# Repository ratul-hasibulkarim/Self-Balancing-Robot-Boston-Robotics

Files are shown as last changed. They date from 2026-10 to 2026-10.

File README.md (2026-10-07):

# BOLT — a cute, 3D‑printable wheel‑legged balancing robot

**BOLT** balances on two wheels at the ends of two legs, like Boston Dynamics' *Handle* or ETH's *Ascento*. It drives fast, leans, crawls, carries a payload and jumps onto curbs. It follows coloured lines (day or night), avoids obstacles and halts when no path exists. It runs GPS missions from **Mission Planner** over the shortest road route, and you drive it from a **phone app**.

| | | |
|---|---|---|
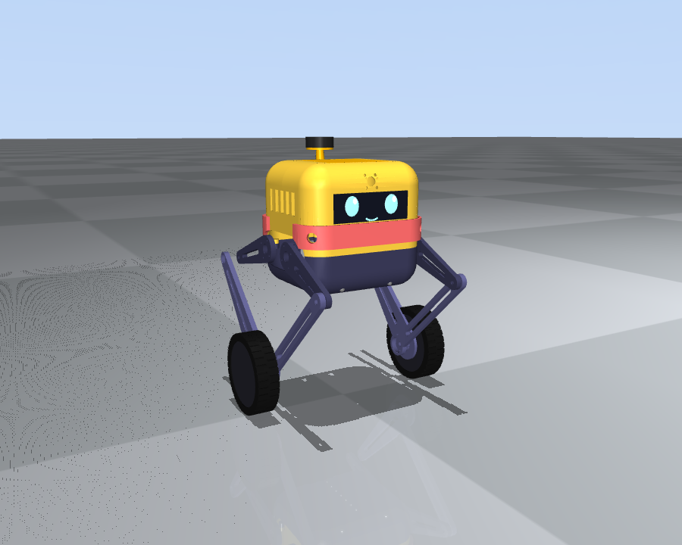
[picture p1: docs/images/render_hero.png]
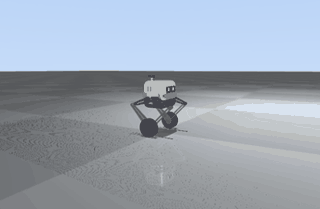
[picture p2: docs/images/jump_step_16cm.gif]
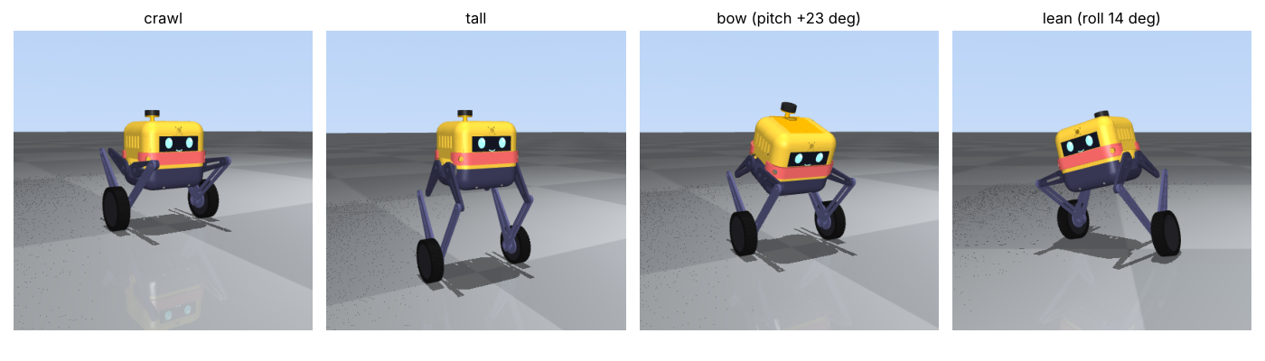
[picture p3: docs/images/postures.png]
|  |  |  |

> Everything here is designed and **tested in simulation** (MuJoCo + the real firmware controller + the real Raspberry Pi code). It has not been built yet. Expect to re‑tune gains on hardware. Read the limits section before you buy motors.

> **New to robotics?** Read the [beginner's guide](docs/guide/README.md). It covers how every part was designed, the physics, the linkages, how the simulations and design iterations were done, and how the electronics and code work.

## What's in this repository

| Deliverable | Where | |
|---|---|---|
| **1. 3D‑printable parts (solid parts)** | `cad/stl/*.stl` (22 parts, print‑oriented) · parametric generator `cad/build_parts.py` · assembly `cad/assembly_nominal_pose.stl` | [print & build guide](docs/05_print_and_build.md) |
| **2. Simulation + test‑driven design iterations** | `sim/` — MuJoCo model, LQR design, 15‑test suite, 3 design iterations, brain‑in‑the‑loop demos | [simulation report](docs/04_simulation_report.md) |
| **3. Control code** | `firmware/` — Teensy 4.1, 1 kHz balance + 5‑bar legs + jump state machine, CAN motor drivers · `companion/` — Raspberry Pi 5 brain (line following, A* routing, obstacle halt, MAVLink) | [software guide](docs/06_software.md) |
| **4. Circuit diagrams and settings** | `electronics/*.svg/.png` · pin maps, motor/Pi/GPS/Mission Planner settings | [electronics & settings](docs/03_electronics_and_settings.md) |
| **5. Controller app** | `app/` — installable phone app (PWA) served by the robot | [software guide §6.4](docs/06_software.md#64-controller-app-app) |
| Design rationale, COM, requirement traceability | | [design overview](docs/01_design.md) · [bill of materials](docs/02_bom.md) |
| **Full explanation for beginners** | physics, mechanism, CAD, simulation & iterations, electronics, code walkthrough | [docs/guide](docs/guide/README.md) |

## The robot in numbers (final design V3, simulation)

* 6.4 kg, 0.49 m tall, 0.40 m wide. Ride height is adjustable from 0.21 to 0.39 m (hip).
* 4 × DM‑J4310 hip actuators drive two 5‑bar legs; 2 × MF9025 hub motors drive the 150 mm wheels. Power is a 6S 5000 mAh LiPo.
* Teensy 4.1 runs the 1 kHz balance loop. Raspberry Pi 5 handles vision, navigation, the app and MAVLink. Two 220° fisheye cameras give 360° coverage.
* Speed: **2.0 m/s** tracked cleanly. Turns at 2 rad/s while doing 1.5 m/s.
* Slopes: **25°** ramps climbed and held. **16°** side slopes with the body kept level.
* Rough ground: **8 cm** bumps at 1.5 m/s. Recovers cleanly from a **10 N·s** shove.
* Payload: **3 kg**, in a bay centred on the hip axis.
* Jumps: **22 cm** wheel clearance. Steps up onto **20 cm** steps (100 % at a 1 m/s run‑up). Hops over **14 cm** obstacles.
* Posture: tilts **±23°**, leans **±15°**, crawls under a **0.42 m** bar.
* Line following: **2.6 cm** mean error, day and night (auto headlight/IR).
* Navigation: A* detours around obstacles, re‑routes around blocked roads, and **halts** if no path exists.

## Limits — read this first

* **Multi‑step stairs don't work reliably.** Single steps and curbs up to 20 cm work. House stairs (25–30 cm treads) fail: there isn't enough run‑up between steps for these hip motors. The fix is stronger hip actuators; see [§4.6](docs/04_simulation_report.md).
* **Self‑righting** from lying flat doesn't work yet. The robot goes limp and you stand it up.
* **Camera‑based step locating is experimental.** Start "Step up" with BOLT 0.5–0.8 m in front of the step.
* Datasheet values to **verify on your parts**: motor bolt patterns, the MF9025 torque constant, and CAN details. They are parameters in the code.

## Quick start

```bash
pip install mujoco numpy scipy matplotlib trimesh manifold3d opencv-python-headless pymavlink aiohttp pyyaml pytest
python3 cad/build_parts.py                    # STLs + mass report
python3 sim/lqr_design.py                     # controller gains (also writes the firmware header)
python3 sim/test_suite.py V3                  # run the 15 requirement tests
python3 sim/companion_sim.py --demo app       # drive the simulated robot from the real app: http://localhost:8080
python3 -m pytest -q companion/tests          # firmware<->Pi link byte compatibility, GPS, A*, re-routing
cd firmware && pio run                        # build the Teensy firmware
```

## Repository map
```
design/      params.py (single source of truth, V1..V3), kinematics.py (5-bar)
cad/         build_parts.py -> stl/, assembly/, mass_report.json
sim/         robot_model.py, lqr_design.py, controller.py (ctypes), simulator.py,
             test_suite.py, companion_sim.py, make_report.py, results/
firmware/    src/main.cpp, src/config.h, lib/bolt_core (controller, shared with sim),
             lib/bolt_drivers (CAN motors, IMU, sonar, eyes), lib/bolt_link, tools/check_build.sh
companion/   robot_brain/ (behaviors, perception, navigation, mission, app_server, link, gps),
             config.yaml, tools/bolt_cli.py, systemd/, tests/
app/         index.html, app.js, style.css, manifest + service worker (PWA)
electronics/ make_diagrams.py -> power_distribution.*, signal_wiring.*
docs/        01_design .. 06_software, images/, guide/ (beginner's guide, 8 chapters)
```

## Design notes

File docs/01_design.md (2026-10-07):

# 1 · Design overview — BOLT

BOLT is a **wheel‑legged balancing robot** in the spirit of Boston Dynamics' *Handle* and ETH's *Ascento*: two legs, each ending in a driven wheel. A leg can change length and angle, so the same machine can **balance like a Segway, crouch, crawl, lean, tilt and jump**.

BOLT

| | |
|---|---|
| Mass | 6.4 kg (body 4.2 kg, legs + wheels 2.2 kg), payload up to 3 kg (sim‑verified), 2 kg design value |
| Size | body 210 × 240 × 230 mm, track 364 mm, overall width 404 mm |
| Height | 0.49 m standing · 0.42 m crawling · hip 0.21–0.39 m (adjustable) |
| Legs | planar 5‑bar per side: hip motors 90 mm apart, thigh 140 mm, shin 250 mm, virtual leg 0.13–0.35 m |
| Actuators | 4 × DM‑J4310‑2EC (hips, 7 Nm peak, CAN) + 2 × LK MF9025v2 hub motors (wheels, 4 Nm, CAN) |
| Wheels | 150 mm, printed PETG‑CF rim + TPU 95A tyre |
| Brains | Teensy 4.1 (1 kHz balance/legs) + Raspberry Pi 5 (vision, navigation, app, MAVLink) |
| Power | 6S LiPo 5000 mAh, slide‑in tray, hot‑swappable |
| Sensing | IMU ICM‑42688‑P, 2 × 220° fisheye cameras (360° view), 4 × ultrasonic, 2 × IR drop‑off sensors, GPS + compass (M10 puck) |

---

## 1.1 Why a wheel‑legged robot?

| Requirement | What the architecture gives |
|---|---|
| Balance on rough / inclined ground | Wheels balance (inverted pendulum); legs act as active suspension and keep the body level (roll compensation on side slopes, pitch on ramps). |
| Run fast | Wheels are 5–10× more efficient and faster than walking legs. |
| Jump steps / obstacles | Both hip motors of a leg push together → 80–165 N per leg (4–8× what it takes to hold the body) → 22 cm wheel clearance in simulation. |
| Tilt / crawl | Leg length 0.13–0.35 m and leg angle are independent → body pitch ±23°, roll ±15°, low crawl stance. |

A pure two‑wheeler can't jump or crawl; a quadruped is slow, heavy and complex. Two legs with wheels is the sweet spot.

## 1.2 Centre of mass — requirement 1

The balance law is an LQR on the "wheel + leg + body" pendulum (see [06_software.md](06_software.md)). What makes it robust on slopes and rough ground is **where the mass sits**:

1. **Fore–aft: on the hip axis.** Battery, payload bay and electronics are arranged so the body COM is within 5 mm of the hip axis in *x*. The leg then stands vertical at rest, the hip motors carry almost no static torque, and acceleration/braking is symmetric.
2. **Vertical: just above the hip axis (+24 mm).** The 780 g battery is slung *below* the hip axis between the hip motors; the payload bay sits *on* the axis. This keeps the body's pitch inertia small (fast attitude control, quick self‑levelling) and means rotating the body relative to the legs (tilt, bow, landing) costs almost no torque.
3. **Lateral: centred, wide track.** 364 mm track and a low whole‑robot COM (0.25 m) give a large lateral stability margin; on side slopes the legs differentially lengthen so the body stays level (sim: < 2° body roll on a 16° side slope).
4. **Leg mass at the top.** The hip motors are on the body, not on the legs (that's the point of the 5‑bar), so the legs are light (0.24 kg of printed links each) and swing fast.

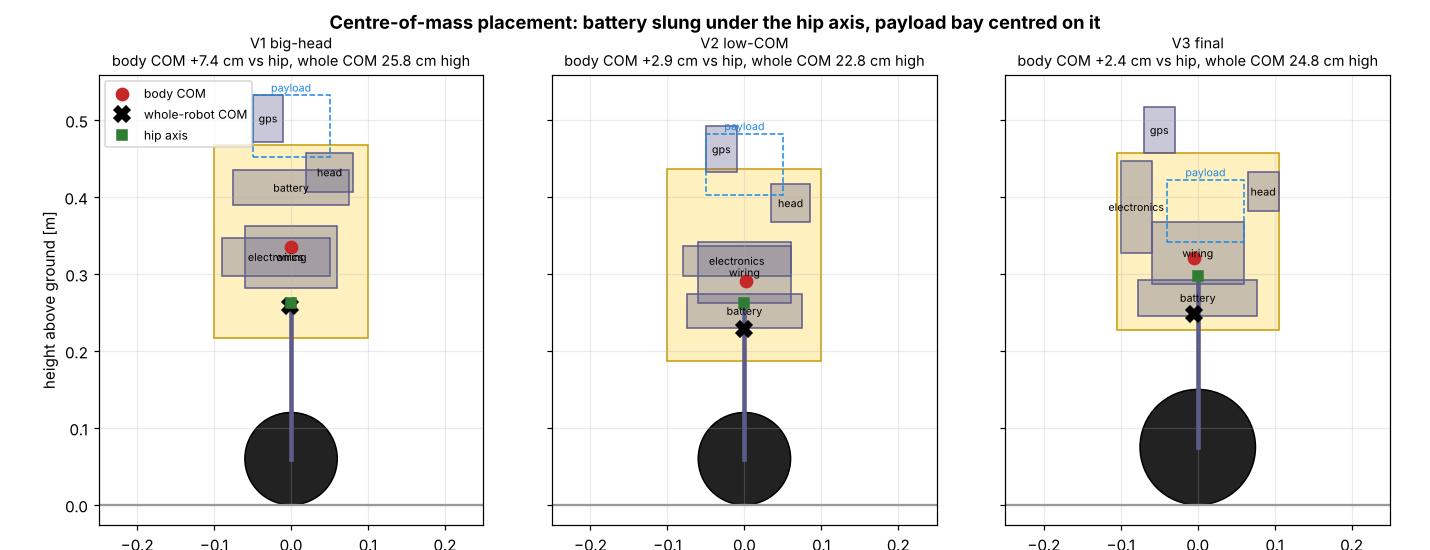
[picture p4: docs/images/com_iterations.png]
COM placement over the three design iterations


The first sketch (V1, "big‑head" — battery and sensors up in the head for a cartoon look) had the body COM 74 mm above the hip; V2 moved the battery under the hip axis (+29 mm); V3 sank the payload bay into the body centre (+24 mm) and grew the wheels. See [04_simulation_report.md](04_simulation_report.md) for what each change bought.

## 1.3 Mechanical layout

```
          GPS puck (stub mast)          payload lid (magnetic)
               |                               |
      +--------+--------- shell (PETG) --------+--------+
      | electronics |      PAYLOAD BAY        | face     |
      |   SLED      |   120 x 124 x 110 mm    | screen,  |
      | (Pi 5,      |   centred on hip axis   | eyes,    |
      |  Teensy,    |                         | fisheye  |
      |  bucks)     |== hip motors (4) ===== =| sonar    |
      |             |  BATTERY 6S (slung low) |          |
      +-----------------  belly pan (PETG-CF) -----------+
             5-bar legs outside the side plates
```

* **Structural core**: two 8 mm PA‑CF side plates carry the four hip motors and are tied by a floor plate (with battery rails) and a top frame. The shell is cosmetic + protective and attaches with 6 × 3 mm magnets — no tools to open.
* **Legs**: per side two thighs (on the hip motors) and two shins meeting at the wheel axle; 608‑2RS bearings at knees and the foot joint; the rear shin carries the wheel motor stator.
* **Bumpers**: TPU 95A "cheeks" front and rear take falls and wall hits; the belly pan has TPU skid ribs.

### Cute character — requirement 3
BOLT is a chunky rounded box ("toaster‑bot") with a dark face screen, two glowing WS2812 ring **eyes** that change expression (normal, happy while jumping, sleepy when off, alert when blocked, angry on error), red bumper "cheeks", and a little antenna stub with the GPS puck. All parts print on a 256 mm bed without supports except the shell openings. See [05_print_and_build.md](05_print_and_build.md).

| front | side | rear / top |
|---|---|---|
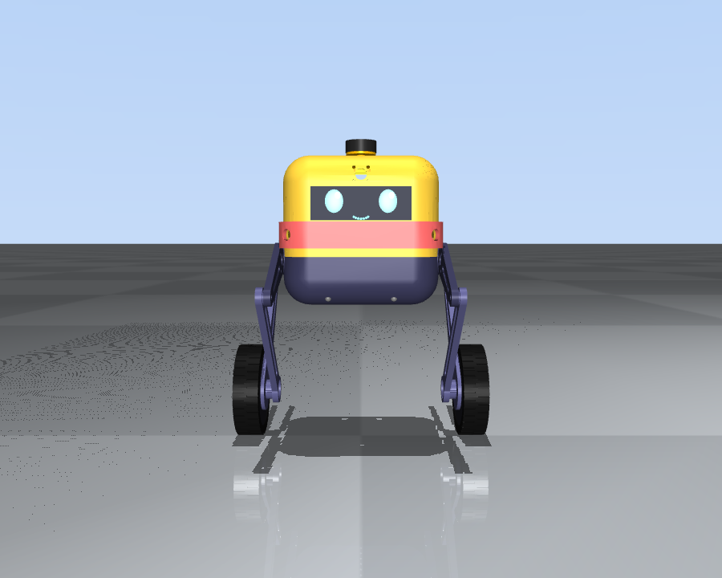
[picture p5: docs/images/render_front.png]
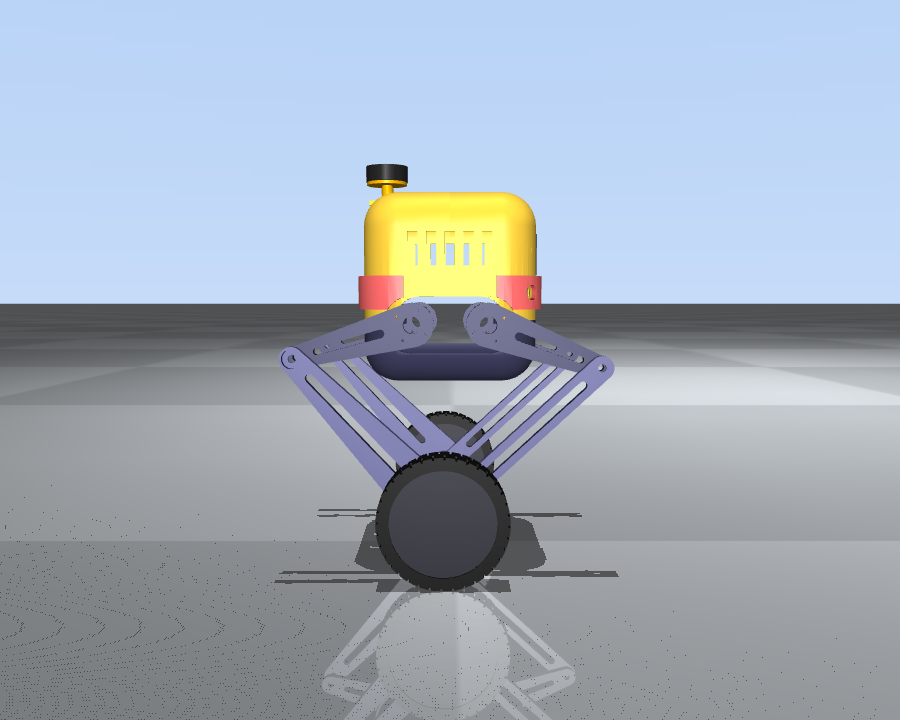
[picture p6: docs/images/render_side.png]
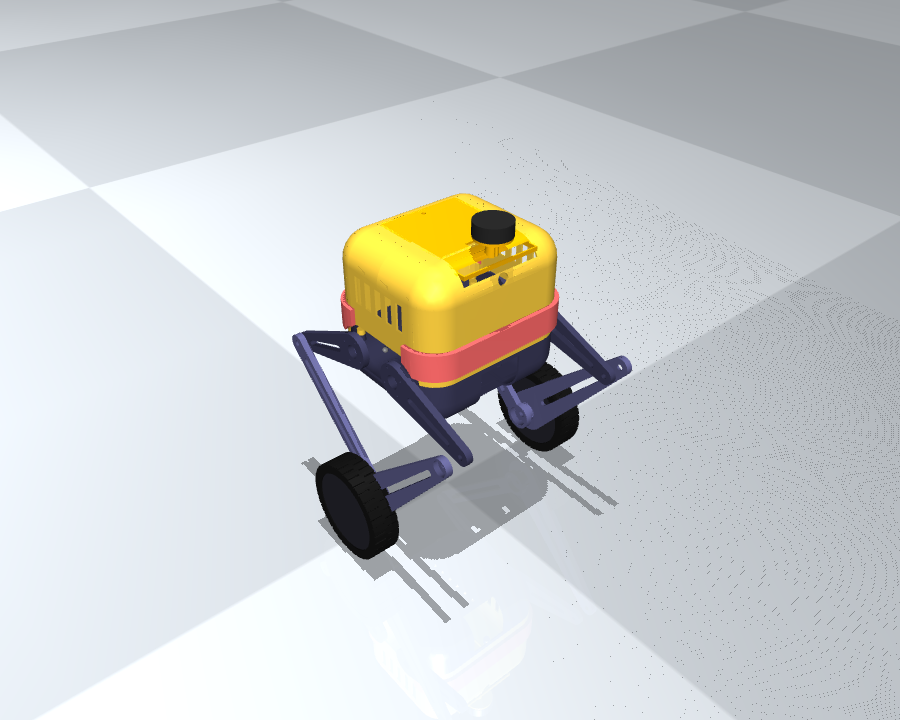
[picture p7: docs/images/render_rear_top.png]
|  |  |  |

## 1.4 Electronics that are handy to remove — requirement 2

* **Electronics sled**: a vertical cartridge (Raspberry Pi 5 on rubber grommets on one face, Teensy carrier with the IMU hard‑mounted + buck converters on the other). It slides into printed guides in the top frame, is clamped by two thumb screws (rigid, so the IMU sees the true body motion) and **pulls straight up** through the roof after lifting the magnetic cap. One 12‑pin locking connector (JST‑GH/Molex Micro‑Fit) + one XT30 carry everything — no loose wires.
* **Battery**: slide‑in tray from the rear with a snap latch; XT90‑S anti‑spark connector.
* **Payload bay**: separate magnetic lid; drain holes and tie‑down eyelets.
* **Motors**: each motor has its own XT30 + 4‑pin CAN JST‑GH pigtail, replaceable without opening the sled.

## 1.5 Cameras — requirement 4: maximum view with minimum cameras

Two **220° M12 fisheye** cameras (Arducam IMX219 NoIR), back‑to‑back at the top front (forehead, 10° down) and rear. Two 220° hemispheres overlap by 40°, so **two cameras see the full 360°** around the robot including the floor right in front of the wheels (needed for line following and step detection). The Pi 5 has exactly two CSI ports. NoIR sensors + 850 nm IR LEDs let them see in the dark.

## 1.6 Fast running without damaging the electronics — requirement 5

| Measure | Where |
|---|---|
| 150 mm wheels: 2 m/s at 70 % of motor no‑load speed (torque reserve for balance) | params / sim |
| Speed‑dependent ride height (lower when fast) and acceleration limit 2.5 m/s² | controller |
| Raspberry Pi on rubber grommets; IMU hard‑mounted but with its on‑chip anti‑alias filter (ODR/10) | CAD / firmware |
| TPU bumpers + TPU tyres (shock absorbing) | CAD |
| Soft landings: leg stroke kept for touchdown, damping doubled in the LAND phase | controller |
| 1000 µF low‑ESR + TVS on the motor bus (regen spikes when braking / landing) | wiring |
| Fall detection → motors limp (no thrashing into the ground) | controller |
| Separate always‑on logic supply; e‑stop only kills motor power | wiring |
| Motor CAN timeout (50 ms), Teensy watchdog (100 ms), Pi command timeout (300 ms) | firmware |
| Battery under‑voltage: slow down, then sit and switch motors off | firmware |

## 1.7 Requirement traceability

| # | Requirement | How BOLT does it | Verified in |
|---|---|---|---|
| 1 | COM for rough / inclined terrain | §1.2, gain‑scheduled LQR, roll levelling | sim: 25° ramps, 16° side slopes, 8 cm bumps at 1.5 m/s |
| 2 | Electronics easy to remove | §1.4 sled + tray + magnetic shell | CAD |
| 3 | Solid, cute, printable | PA‑CF structure, TPU bumpers, expressive eyes | CAD (all parts ≤ 256 mm, watertight STLs) |
| 4 | Cameras with max visibility | 2 × 220° fisheye = 360° | sim camera, line following |
| 5 | Run fast safely | §1.6 | sim: 2.0 m/s clean, turning 2 rad/s at 1.5 m/s |
| 6 | Jump steps / obstacles of variable height & distance | energy‑planned jump with edge‑distance timing | sim: step‑ups to 20 cm, hop 14 cm obstacle, flat jump 22 cm clearance (multi‑step stairs: see limits) |
| 7 | Tilt at variable angles / crawl | posture commands | sim: pitch ±23°, roll ±15°, crawl under 0.42 m |
| 8 | Carry a payload | sunken bay on the hip axis | sim: 3 kg drive + push |
| 9 | Avoid obstacles, run in the dark, follow coloured lines (no lidar) | sonar occupancy grid + A*, vision line follower + auto headlight/IR | SIL sim (real brain code) |
| 10 | Halt if no alternative path | local A* → turn‑and‑scan → road re‑route → HALT + report | SIL sim "boxed in" |
| 11 | Mission Planner GPS missions, shortest path | MAVLink rover endpoint + A* on a road graph | SIL sim with a pymavlink GCS |
| 12 | Phone controller: jump, dodge, tilt, climb… | PWA app served by the robot | headless browser test vs. sim |

## 1.8 Known limits (honest list)

* **Multi‑step stairs are not reliable.** Single steps/curbs up to 20 cm work every time in simulation at a 1 m/s approach. Consecutive hops need a 0.6 m+ landing between steps and even then fail intermittently on the final design (front knee clips the edge after a short run‑up). Normal house stairs (0.25–0.30 m treads) are **not** supported by this actuator set. Fix path: stronger hip actuators (e.g. DM‑J8009) for a standing‑start lunge jump, or a "knees‑back" leg variant.
* **Self‑righting** from lying flat is implemented but does not work yet in simulation — the robot goes limp (protecting itself) and waits for you to stand it up.
* **Autonomous step locating** (front camera → distance to a step edge) is experimental: accurate to ~2 cm at 0.5–0.9 m, but the full "Step up" action only works reliably when started ~0.7 m in front of the step.
* All results are **simulation** (MuJoCo + the real controller code + motor torque/speed limits + sensor noise/latency). Expect to re‑tune gains on the real robot ([06_software.md](06_software.md) §bring‑up).
* Motor bolt patterns, the MF9025 torque constant and CAN details are from datasheets of the versions I know; **verify against the batch you buy** (they're parameters in `cad/build_parts.py` and `firmware/src/config.h`).

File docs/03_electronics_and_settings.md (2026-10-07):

# 3 · Electronics, wiring and settings

Diagrams are generated by `electronics/make_diagrams.py` (SVG + PNG). Pin numbers come from `firmware/src/config.h` — if you change one, change both.

## 3.1 Power distribution

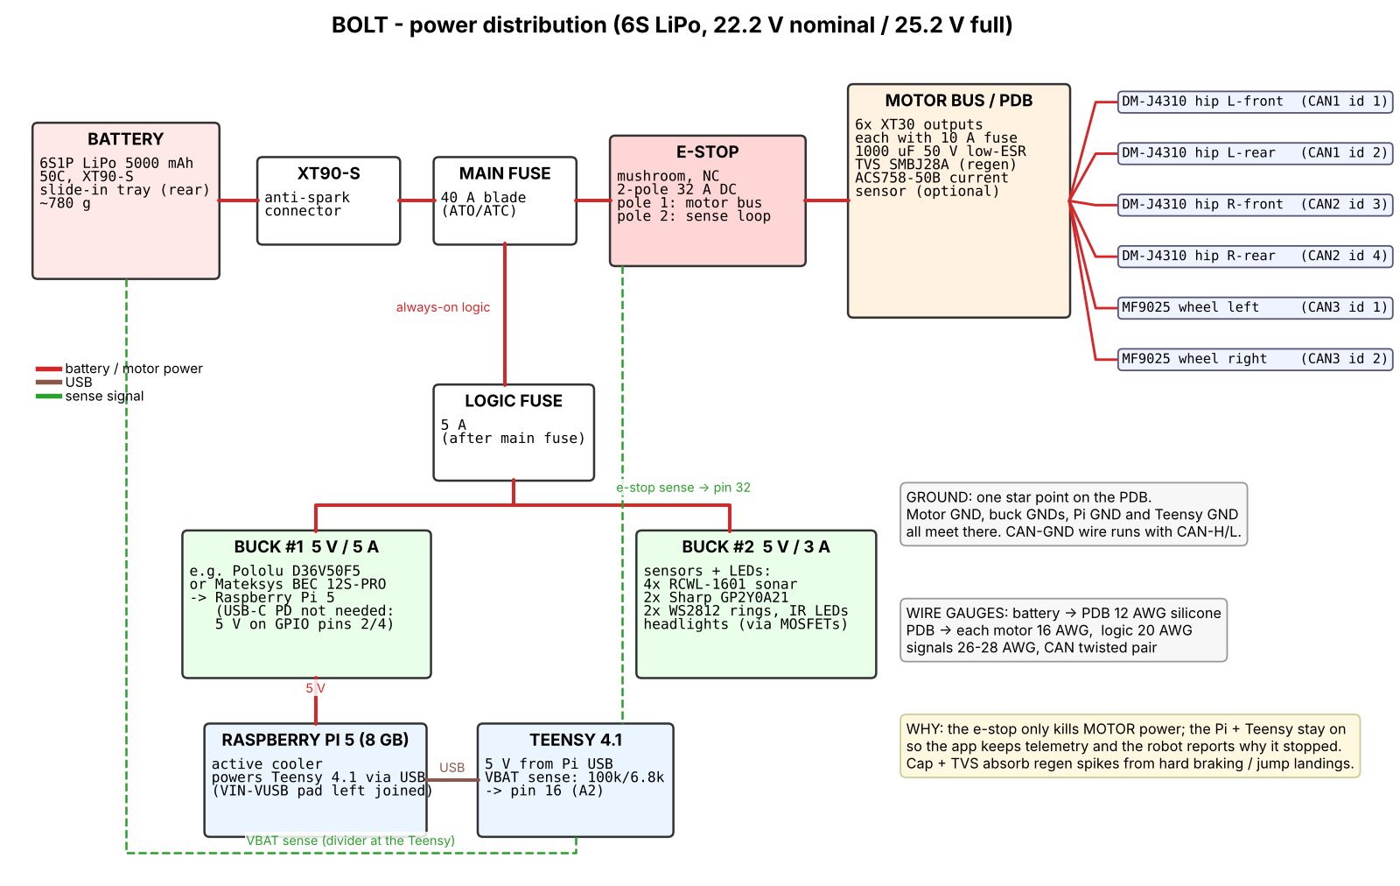
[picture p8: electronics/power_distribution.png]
power


* **One star ground** on the PDB. Never ground the Pi or Teensy through a different path than their supply.
* The **e‑stop cuts only motor power**. Pi + Teensy stay alive (logic fuse is upstream of the e‑stop), so the app still shows telemetry and why the robot stopped. Pole 2 of the e‑stop opens a sense loop on Teensy pin 32 → the controller also commands zero torque.
* **Regen protection**: hard braking and jump landings push current back into the bus. The 1000 µF low‑ESR capacitor and the SMBJ28A TVS at the PDB clamp the spikes (DM motors are rated 24 V nominal; a full 6S pack is 25.2 V — do **not** go to 8S).
* Pi 5 is fed 5 V directly on GPIO pins 2/4 (5 V) and 6 (GND) from a 5 A buck. Add `usb_max_current_enable=1` to `config.txt` (see §3.5), otherwise the Pi limits USB current because there is no USB‑PD negotiation.

## 3.2 Signal wiring

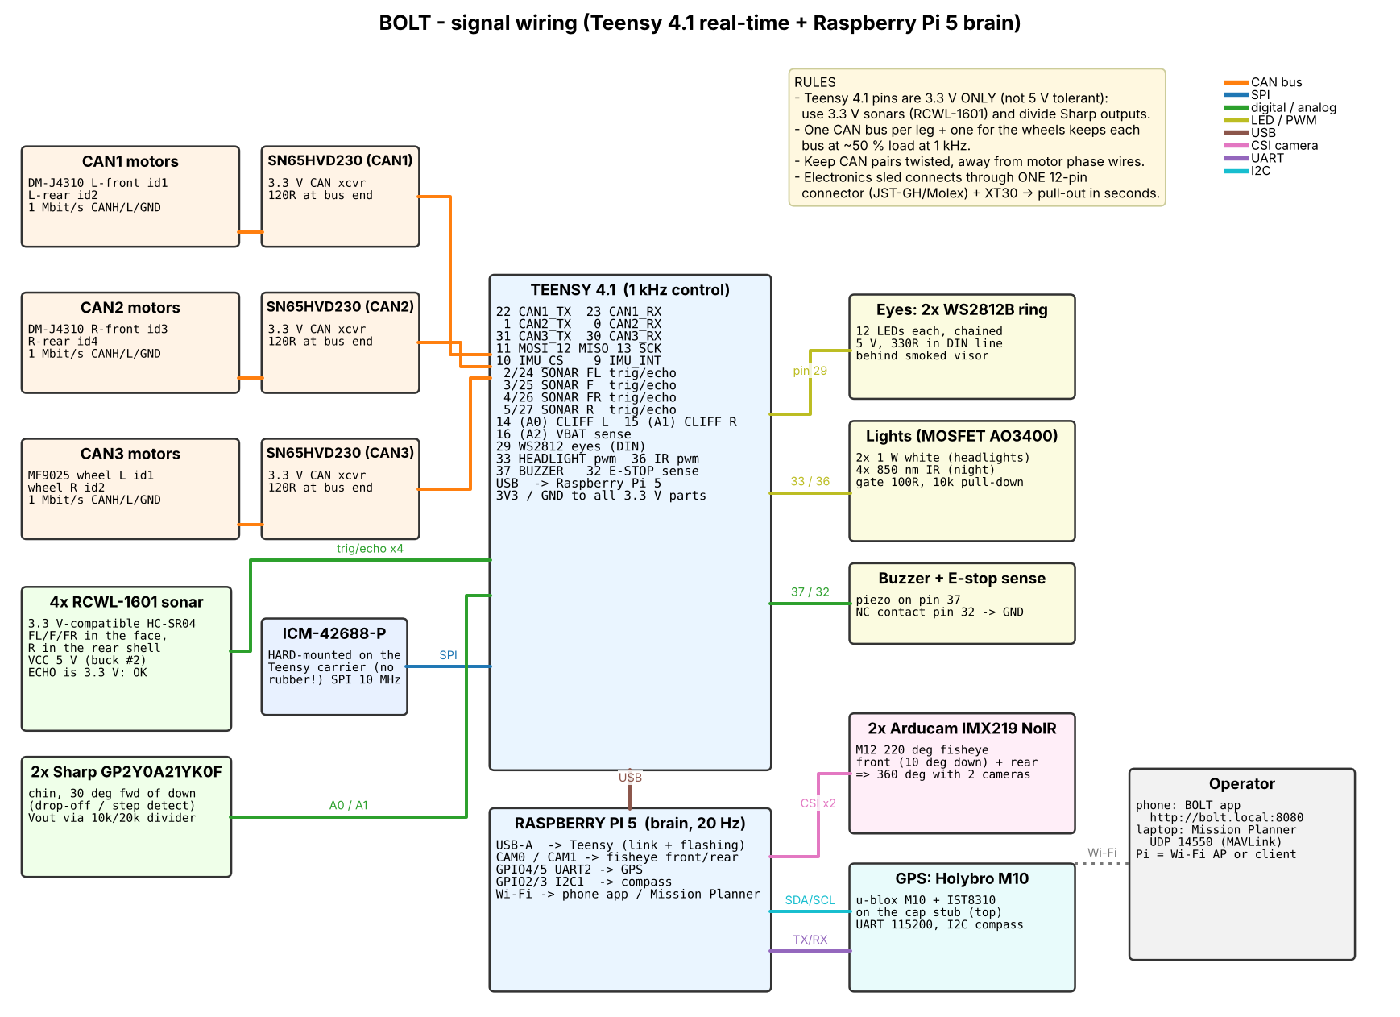
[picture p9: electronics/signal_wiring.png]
signals


### Teensy 4.1 pin map
| Pin | Function | Pin | Function |
|---|---|---|---|
| 22 / 23 | CAN1 TX / RX → left hips | 2 / 24 | sonar FL trig / echo |
| 1 / 0 | CAN2 TX / RX → right hips | 3 / 25 | sonar F trig / echo |
| 31 / 30 | CAN3 TX / RX → wheels | 4 / 26 | sonar FR trig / echo |
| 11 / 12 / 13 | SPI MOSI / MISO / SCK (IMU) | 5 / 27 | sonar Rear trig / echo |
| 10 / 9 | IMU CS / INT | 14 (A0) / 15 (A1) | Sharp cliff L / R (via 10k/20k divider) |
| 29 | WS2812 eyes DIN (330 Ω series) | 16 (A2) | VBAT sense (100k / 6.8k) |
| 33 | headlight PWM → AO3400 | 32 | e‑stop sense (INPUT_PULLUP, loop to GND) |
| 36 | IR LEDs PWM → AO3400 | 37 | buzzer |
| USB | Raspberry Pi (link + power + flashing) | 3V3 | IMU, CAN transceivers, sonar logic |

> Teensy 4.1 I/O is **3.3 V only**. That's why the sonars are RCWL‑1601 (3.3 V HC‑SR04 variant) and the Sharp outputs go through a divider.

### Raspberry Pi 5 connections
| Pi | Connected to |
|---|---|
| USB‑A (any) | Teensy 4.1 micro‑USB → `/dev/ttyACM0` |
| CAM0 / CAM1 (22‑pin) | front / rear fisheye camera |
| GPIO4 (TXD2) / GPIO5 (RXD2) | GPS RX / TX (UART2 → `/dev/ttyAMA2`) |
| GPIO2 (SDA1) / GPIO3 (SCL1) | GPS puck compass IST8310 (I²C 0x0E) |
| pins 2/4 + 6 | 5 V / GND from buck #1 |
| Wi‑Fi | phone app + Mission Planner |

### CAN buses
* **3 buses at 1 Mbit/s**: CAN1 = left hip motors (IDs 1, 2), CAN2 = right hip motors (IDs 3, 4), CAN3 = wheel motors (IDs 1, 2). At 1 kHz each bus carries 4 frames/ms ≈ 50 % load.
* Daisy chain each bus with twisted pair + a GND wire. **120 Ω at both ends**: most SN65HVD230 breakouts already have one (keep it at the Teensy end) and put one at the last motor (DM motors have a termination switch / solder pad).

## 3.3 Motor settings

### DM‑J4310‑2EC (Damiao debugging assistant, USB‑CAN adapter)
| Setting | Value |
|---|---|
| Control mode | **MIT** |
| CAN ID (slave) | 0x01 L‑front, 0x02 L‑rear, 0x03 R‑front, 0x04 R‑rear |
| Master ID (feedback) | 0x11 / 0x12 / 0x13 / 0x14 |
| Baud | 1 Mbit/s |
| PMAX / VMAX / TMAX | 12.5 rad / 30 rad/s / 10 Nm |
| CAN timeout | 50 ms (motor disables itself if commands stop) |
| Over‑temperature | 80 °C (default) |

Firmware sends pure torque (`kp = 0`, small `kd = 0.02` for smoothness). **Direction**: `HIP[i].sign` in `config.h` maps motor rotation to the controller's φ convention (CCW in the leg plane seen from the robot's right). After calibration, run `bolt_cli.py status`, move a leg by hand: extending the leg must *increase* L.

### LK‑TECH MF9025v2 (LK motor tool)
| Setting | Value |
|---|---|
| ID | 1 = left, 2 = right (frame id 0x141 / 0x142) |
| Bus | CAN, 1 Mbit/s |
| Control | torque loop, command 0xA1 (iq) |
| Protection | enable "communication interruption" stop (100 ms) |
| Firmware constants | `WHEEL_KT` (Nm/A) and `WHEEL_IQ_FULLSCALE_A` — **check your datasheet**; wrong values only scale the gains, but check the sign: positive wheel torque must roll the robot forwards |

## 3.4 Firmware settings (`firmware/src/config.h`)
* `CONTROL_HZ 1000`, `TELEMETRY_HZ 100`, `CMD_TIMEOUT_S 0.3` (no command → stop and hold balance).
* `CAL_PHI1/CAL_PHI4`: thigh angles in the calibration pose (legs folded on the printed end stops). Computed from the kinematics; don't change unless you change the legs.
* `BATT_LOW_V 21.0` (slow down), `BATT_CRIT_V 19.8` (motors off).
* `IMU_AXIS_MAP / IMU_AXIS_SIGN`: map the IMU chip axes to body axes (x forward, y left, z up).
* Gains: `firmware/lib/bolt_core/robot_config_generated.h` is **generated** by `python3 sim/lqr_design.py` — edit `design/params.py` / the weights in `sim/lqr_design.py`, not the header.

## 3.5 Raspberry Pi OS (Bookworm 64‑bit)
`/boot/firmware/config.txt` additions:
```ini
# cameras (two IMX219 on CAM0/CAM1)
camera_auto_detect=0
dtoverlay=imx219,cam0
dtoverlay=imx219,cam1
# GPS on UART2 (GPIO4/5) -> /dev/ttyAMA2, compass on I2C1
dtoverlay=uart2-pi5
dtparam=i2c_arm=on
# powered through the GPIO 5 V pins by a 5 A buck
usb_max_current_enable=1
```
Then:
```bash
sudo hostnamectl set-hostname bolt          # app at http://bolt.local:8080
sudo apt install -y python3-opencv python3-picamera2 python3-serial python3-yaml python3-aiohttp python3-numpy
pip install --break-system-packages pymavlink
sudo usermod -aG dialout,video bolt
# Wi-Fi hotspot for the field (phone + laptop join "BOLT"):
sudo nmcli dev wifi hotspot ifname wlan0 ssid BOLT password "bolt-robot"
sudo cp companion/systemd/bolt.service /etc/systemd/system/ && sudo systemctl enable --now bolt
```

## 3.6 GPS (u-blox M10, u‑center 2, once)
* UART1 baud **115200**, output **NMEA** GGA + RMC + GSA (disable GSV/GLL/VTG to save bandwidth).
* Navigation rate **10 Hz** (M10 supports 10 Hz with GPS+Galileo+BeiDou; drop GLONASS if needed).
* Dynamic platform model **Pedestrian** (good for ≤ 3 m/s ground robots), SBAS on.
* Save configuration to flash/BBR.
* Mount the puck on the cap stub (top of the robot) — as far from the motors as possible; the compass (IST8310) is optional for BOLT (heading is fused from IMU yaw + GPS course).

## 3.7 Mission Planner (ArduPilot GCS)
1. Laptop joins the robot's Wi‑Fi (or the same LAN). In `companion/config.yaml` set `mavlink.url` to `udpout:<laptop-ip>:14550` (or keep the broadcast default).
2. Mission Planner → top right: **UDP**, port **14550**, Connect. BOLT appears as a *Rover* (sysid 1) on the map with heading, speed, GPS and battery.
3. **Plan** tab → set Home, click waypoints → **Write WPs**. Supported: `WAYPOINT`, `LOITER_TIME`, `RETURN_TO_LAUNCH`, `CONDITION_DELAY`, `DO_JUMP`, `DO_CHANGE_SPEED`, plus `USER_1` (BOLT jump: p1 height m, p2 0=onto/1=over), `USER_2` (height/crawl), `USER_3` (tilt: p1 pitch°, p2 roll°).
4. **Data** tab → Actions: **Arm**, mode **Auto** (or "Mission Start"). `Hold` pauses, `RTL` returns home, right‑click → **Fly to here** = GUIDED go‑to.
5. Between waypoints BOLT drives the **shortest route over the road graph** (`companion/maps/roads.geojson`, export OSM `highway=*` lines for your area with QGIS/overpass‑turbo) with A*; it detours around obstacles, re‑routes around blocked roads and **halts with a status text** if no alternative exists.

## 3.8 First‑time calibration
1. Power with the **e‑stop pressed** (motors unpowered), connect to the Pi: `sudo systemctl stop bolt`.
2. `python3 tools/bolt_cli.py calibrate` with both legs folded against the printed end stops → offsets stored in Teensy EEPROM. The eyes stop being "angry" (uncalibrated) and turn normal.
3. `python3 tools/bolt_cli.py status`: tilt the robot nose‑down → pitch must go **positive**; roll left side up → roll positive; extend a leg by hand → L increases.
4. `tools/bolt_cli.py sonar` → check all four sonars and both cliff sensors.
5. Release the e‑stop, hold the robot upright on the floor, `tools/bolt_cli.py balance 10`. It should stand still; if it runs away, a sign in `config.h` is wrong (wheel or hip `sign`, or IMU map).

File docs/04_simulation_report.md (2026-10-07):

# 4 · Simulation, testing and design iterations

## 4.1 How the robot was simulated

* **Physics**: MuJoCo 3 (0.5 ms step, implicit integrator, elliptic friction cones). The model (`sim/robot_model.py`) is generated from `design/params.py` and the CAD mass report: a floating body, **closed‑chain 5‑bar legs** (equality constraints), real tyre/ground contact, the GPS puck and shins as colliders.
* **Controller = firmware**: `firmware/lib/bolt_core/bolt_controller.cpp` is compiled into a shared library and called through ctypes at 1 kHz — the simulator runs the exact code that is flashed onto the Teensy.
* **Realism added**: linear torque–speed envelopes of both motor types (back‑EMF limits), one control period of CAN latency, IMU/encoder noise, a speed‑dependent wheel velocity estimate, simulated ultrasonic cones, IR cliff sensors, a rendered front camera and a wandering virtual GPS.
* **Brain in the loop** (`sim/companion_sim.py`): the real Raspberry Pi code (`companion/robot_brain`) drives the simulated robot — line following from rendered images, A* obstacle detours, Mission Planner missions over real MAVLink/UDP, and the phone app over WebSocket.

Reproduce everything: see [06_software.md §6.5](06_software.md).

## 4.2 Design iterations

| | V1 "big head" | V2 "low COM" | V3 final |
|---|---|---|---|
| Idea | cartoon proportions: battery + sensors in the head | battery slung under the hip axis, wider track (300 → 364 mm) | 150 mm wheels, longer shins (jump stroke), payload bay sunk onto the hip axis, printed parts from CAD |
| Body COM above hip axis | +74 mm | +29 mm | +24 mm |
| Whole‑robot COM height | 0.26 m | 0.23 m | 0.25 m |
| Wheel Ø | 120 mm | 120 mm | **150 mm** |
| Mass | 5.7 kg | 5.7 kg | 6.4 kg |

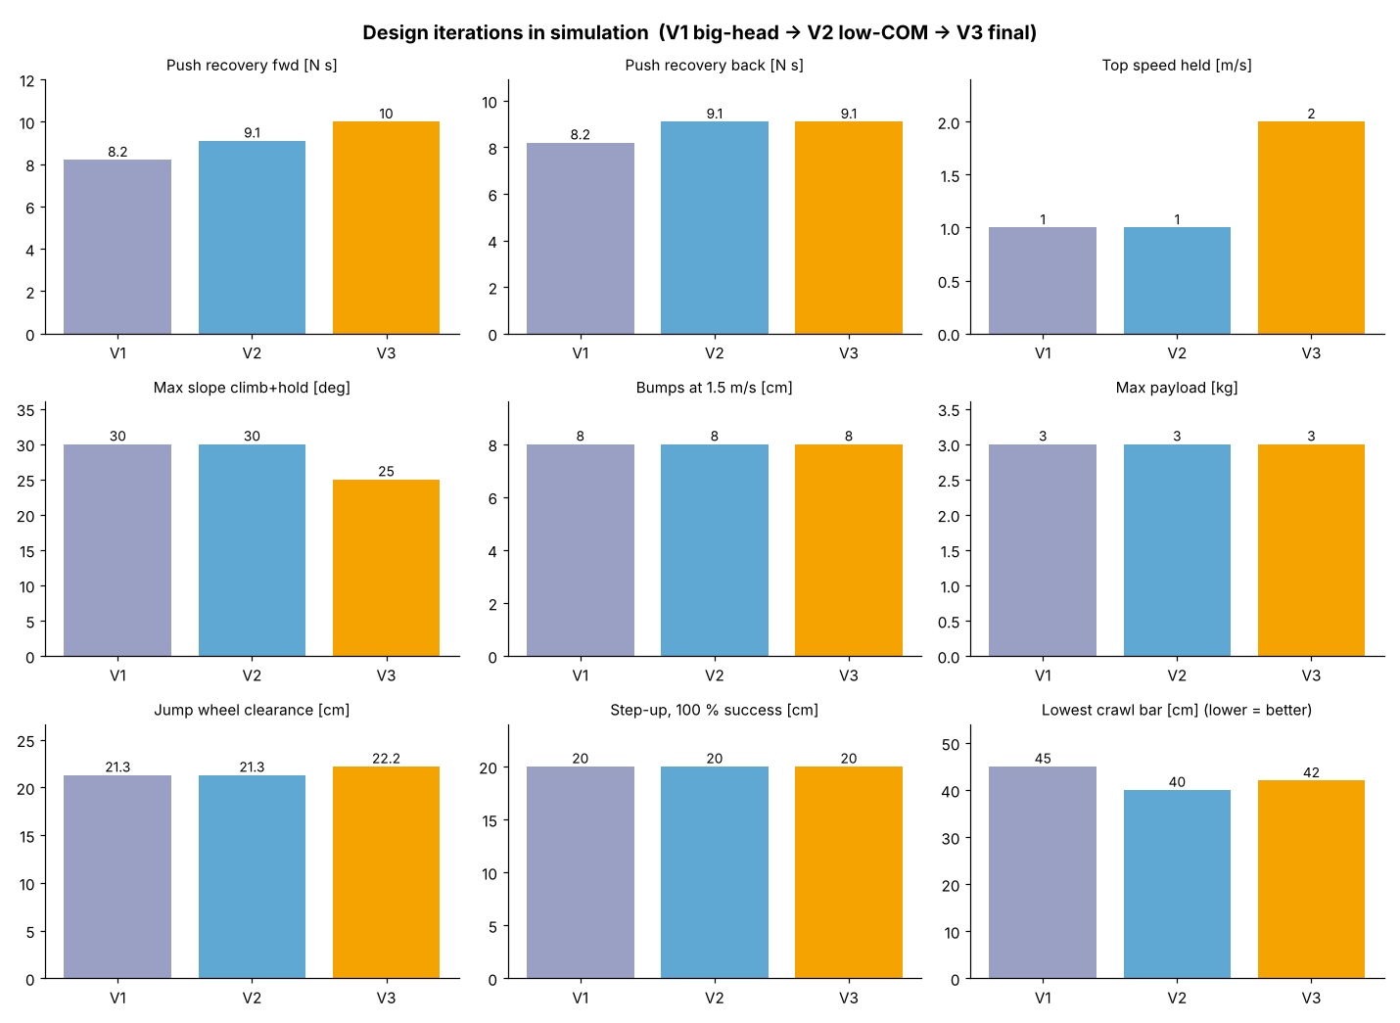
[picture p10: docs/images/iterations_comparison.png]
iterations


What each step bought (from the test suite, same controller design procedure for all variants):

* **V1 → V2 (lower COM)**: clean push recovery 8.2 → 9.1 N·s; the body attitude loop gets less disturbed by leg motion; lower crawl (45 → 40 cm bar). 
* **V2 → V3 (bigger wheels, longer legs, centred payload)**: **safe top speed 1.0 → 2.0 m/s** — with 120 mm wheels the hub motors hit their back‑EMF limit near 2 m/s, run out of balancing torque and the robot runs away (V1 tips over at 34°, V2 reaches 3 m/s out of control). With 150 mm wheels 2 m/s uses ~70 % of the motor speed and the robot tracks 2.0 m/s with < 0.5° body pitch. Also push recovery 10 N·s forward, flat‑jump wheel clearance 21 → 22 cm.
* **The price**: the same motor torque on a larger wheel gives less traction force, so the steepest ramp it climbs *and* holds drops from 30° to 25° (still above the 20° target), and V3 is 0.7 kg heavier.
* **Unchanged across variants**: 8 cm bumps at 1.5 m/s, 3 kg payload, ±23° pitch / ±15° roll, 20 cm step‑ups — these are set by the controller and the leg actuators, not by these geometry changes.

### Controller iterations (found by the tests, fixed in the firmware)
| Problem seen in simulation | Fix in `bolt_controller.cpp` |
|---|---|
| First jump: abrupt crouch tipped the leg, thrust ended early, touchdown never detected → fall | smooth crouch ramp, wait until legs are vertical, energy‑planned thrust over the full stroke |
| Touchdown falsely detected mid‑air from internal leg forces (accelerometer) | touchdown = leg compression while the detector is armed after apex |
| Body spins nose‑down after take‑off | feed‑forward hip torque cancelling the leg force's moment about the body COM; wheel torque limited during thrust; legs held in the body frame in flight |
| Wheels clipped the step lip after extending for landing | separate jump modes: *onto a step* (stay tucked) vs *over an obstacle* (extend after apex) |
| Narrow timing window for step jumps (crouch duration varies) | controller times the take‑off from the edge distance + its own odometry; aborts instead of hitting the riser |
| Front knee strikes the step edge | take‑off distance includes the knee overhang (`JUMP_EDGE_MARGIN`) |
| Robot overshoots speed commands after braking ("catch‑up") | position reference re‑anchored when starting/reversing, kept when stopping (still holds on slopes) |
| Turns at half the commanded rate (tyre scrub) | yaw‑rate PI instead of P |
| Push test passed while legs had flailed through 120° | stricter test: must settle back to a calm stance → honest 10 N·s figure |

## 4.3 Final design (V3) results

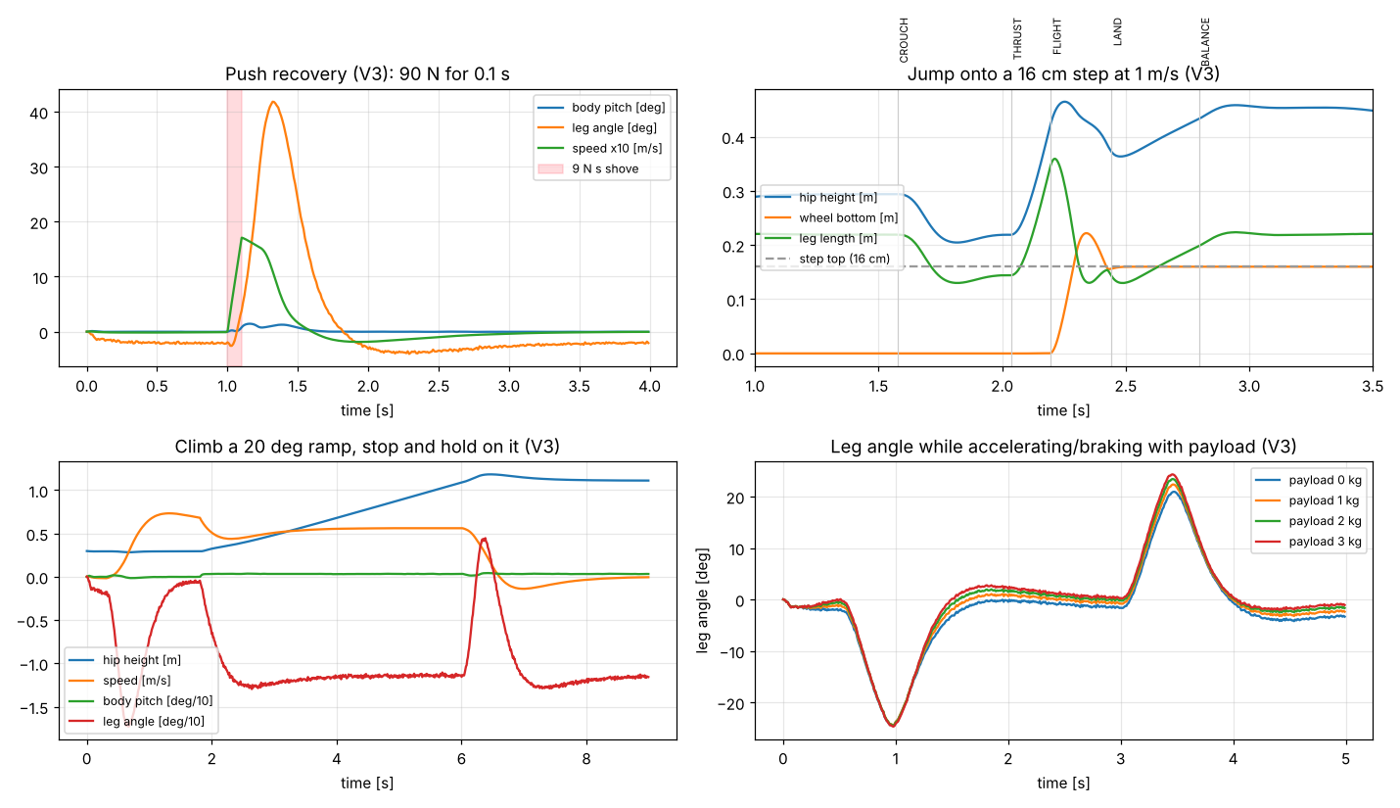
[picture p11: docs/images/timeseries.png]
time series


| Test (requirement) | Result | |
|---|---|---|
| Static balance (1) | 0.02° RMS pitch, 4 mm drift with sensor noise | ✅ |
| Push recovery, clean (1, 5) | 10 N·s forward / 9 N·s backward (≈ 1.5 m/s kick) | ✅ |
| Top speed (5) | 2.0 m/s tracked, < 0.5° pitch; 2.4 m/s runs away (motor limit) | ✅ |
| Turning at speed (5) | 2 rad/s at 1.5 m/s, 0.2° body roll | ✅ |
| Ramps (1) | climbs **and holds** 25°; 30° fails | ✅ |
| Side slopes (1) | 16° side slope, body kept within 1.8° of level | ✅ |
| Rough ground (1) | 8 cm random bumps at 1.5 m/s; 11 cm at 0.8 m/s | ✅ |
| Payload (8) | 3 kg in the bay: drives 1 m/s and survives an 8 N·s push | ✅ |
| Tilt (7) | pitch −23…+23°, roll ±15°, hip height 0.21–0.39 m | ✅ |
| Crawl (7) | passes under a 0.42 m bar | ✅ |
| Jump (6) | 22 cm wheel clearance, planned vs achieved within ~1 cm up to the motor limit | ✅ |
| Step‑up at 1 m/s (6) | **100 %** for 8, 12, 16, 20 cm (3 request distances each); 22 cm 1/3 | ✅ |
| Hop over an obstacle (6) | 6, 10, 14 cm high bars | ✅ |
| Stairs, 3 steps (6) | ❌ on V3 (V1/V2 manage 0.6 m treads); standard 0.25–0.30 m treads fail on all | ❌ |
| Self‑righting | ❌ experimental, robot goes limp and waits | ❌ |

| Step‑up onto 16 cm | Hop over a 14 cm bar | 8 cm bumps at 1.5 m/s | Crawl under 0.42 m |
|---|---|---|---|
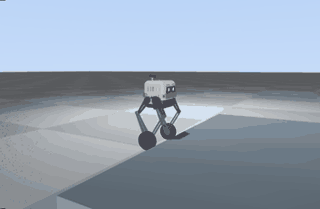
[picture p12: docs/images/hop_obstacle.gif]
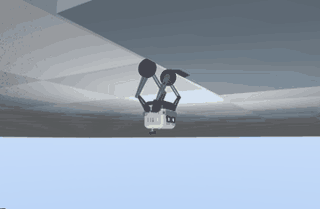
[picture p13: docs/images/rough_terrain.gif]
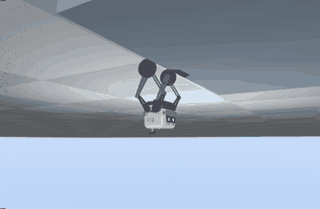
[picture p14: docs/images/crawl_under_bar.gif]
|  |  |  |  |

postures

## 4.4 Brain‑in‑the‑loop results (requirements 9–12)

| Scenario | Result |
|---|---|
| **Line following**, red line with S‑bends, daylight | 26.5 m in 40 s, **2.6 cm mean** / 21 cm max deviation |
| **Line following in the dark** | headlight + IR switched on automatically, 2.6 cm mean deviation |
| **Obstacle detour** (wall across the path, gap at the side) | A* detour, goal reached |
| **Boxed in** (goal unreachable) | scans 360°, then **HALT: "no alternative path"** reported to app/GCS |
| **Mission Planner mission** (pymavlink GCS: upload 4 items, arm, start) over a street grid, broken‑down van on the shortest route | shortest street routes, local detour around the blocked street via the next block, **mission complete**; GCS sees position/heading/status texts throughout |
| **Phone app** (headless Chromium vs. the simulated robot) | connect, drive 1.3 m/s, Jump → CROUCH/THRUST/FLIGHT/LAND, crawl, waypoint, E‑STOP; no JS errors |
| **Vision step locator** (camera → distance to a step edge) | ≤ 2 cm error 0.5–0.9 m away; full "Step up" action works when started ~0.7 m from the step (3/3 heights); from other start distances unreliable (own shadow, edge mis‑pairing at long range) → **experimental** |

| line following (day) | at night (auto headlight) | what the robot's camera sees |
|---|---|---|
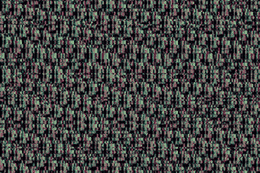
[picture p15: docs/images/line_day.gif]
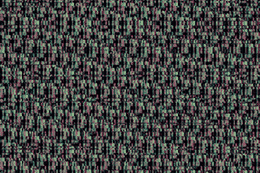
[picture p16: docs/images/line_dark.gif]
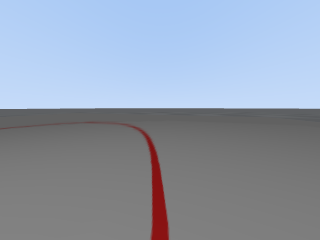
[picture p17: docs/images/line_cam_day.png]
|  |  |  |

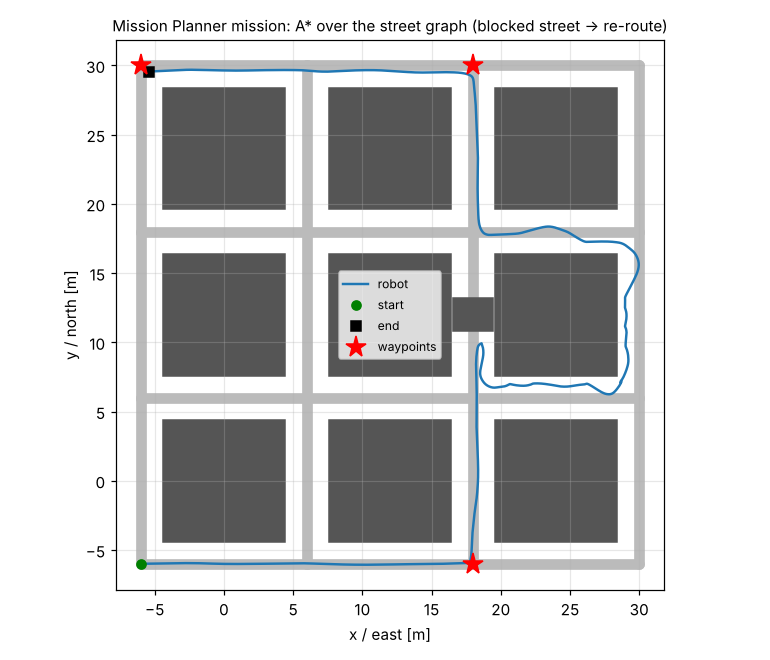
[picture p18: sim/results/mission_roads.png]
mission


| detour | boxed in → HALT |
|---|---|
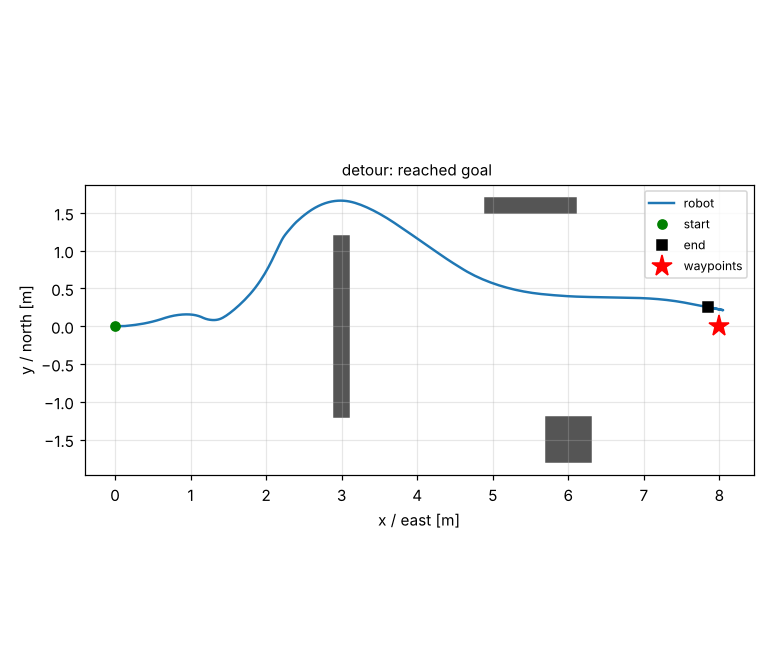
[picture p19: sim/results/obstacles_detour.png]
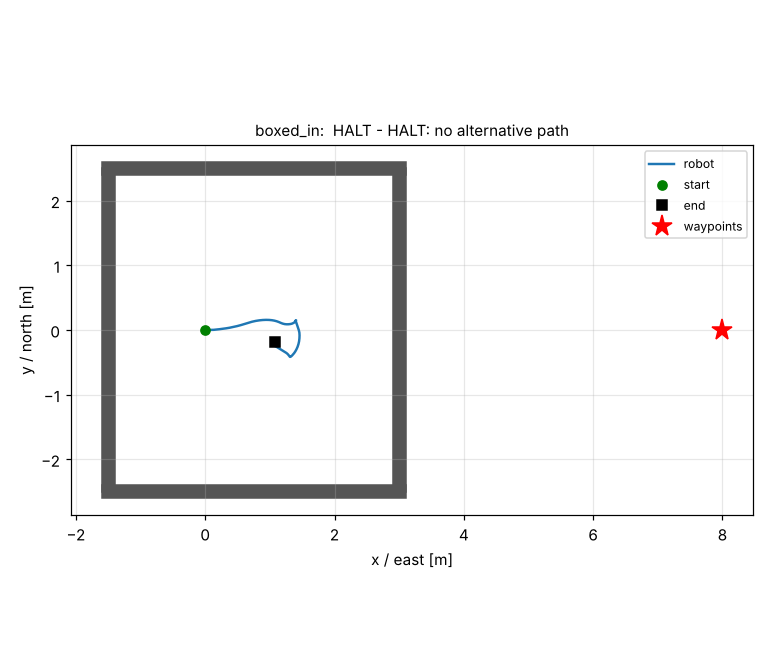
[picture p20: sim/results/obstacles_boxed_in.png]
|  |  |

## 4.5 What simulation can't tell you
Tyre/ground friction, gearbox backlash, CAN timing jitter, cable drag on the legs, real fisheye distortion and lighting, and printed‑part flex are idealised. Plan on re‑tuning the leg spring/damper and the LQR weights on the real robot, and start jumping at low heights on soft ground. The gains are regenerated in seconds from `design/params.py` once you weigh the real parts.

## 4.6 Next steps (to close the open items)
1. **Stairs**: stronger hip actuators (e.g. DM‑J8009, ~3× torque) → standing‑start lunge jumps; or knees‑back legs so the knee doesn't overhang the wheel.
2. **Self‑righting**: a dedicated motion (swing both legs over the head to lever the body) — needs leg‑vs‑shell clearance checks in CAD first.
3. **Step locator**: higher camera resolution for the locator crop, fisheye undistortion, temporal edge tracking that rejects the robot's own shadow.

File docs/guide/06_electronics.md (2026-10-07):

# Chapter 6 — How the electronics work

Wiring diagrams: [`electronics/power_distribution.png`](../../electronics/power_distribution.png) and [`electronics/signal_wiring.png`](../../electronics/signal_wiring.png). Pin numbers: [`firmware/src/config.h`](../../firmware/src/config.h).

## 6.1 Three ideas you need
* **Voltage (V)** is "pressure", **current (A)** is "flow", **power (W) = V × A**.
* Wires and fuses are sized for **current**. Electronics are damaged by the wrong **voltage**.
* Every circuit needs a return path. All grounds (0 V) must be connected, at **one point**.

## 6.2 The battery
**6S LiPo**: six lithium cells in series, 3.7 V each nominal → 22.2 V (25.2 V full, ~19.8 V empty). The hip motors are rated for 24 V systems, so 6S is the right match; 8S (33.6 V) would damage them. 5000 mAh × 22.2 V = **111 Wh** of energy.

**Power budget (estimates):**

| Situation | Power | Current at 22 V |
|---|---|---|
| Pi 5 + cameras + Teensy + sensors | ~12 W | 0.5 A |
| standing and balancing (hips holding ~1.8 Nm each) | ~30–50 W | 2 A |
| driving 1–2 m/s | ~60–100 W | 3–5 A |
| jump burst (4 hips near 7 Nm and 10 rad/s + wheels) | ~500–600 W for 0.2 s | ~25 A |

So expect roughly **1–1.5 hours** of mixed use. A "50C" 5 Ah pack can deliver 250 A, so the bursts are no problem for the battery.

## 6.3 The power path, step by step
1. **XT90‑S anti‑spark connector.** Plugging a battery into big capacitors causes a spark that pits the connector. The "S" version has a resistor that pre‑charges them first.
2. **Main fuse, 40 A.** Protects the wiring if something shorts. 12 AWG silicone wire handles 40 A comfortably. A slow‑blow blade fuse doesn't trip on 0.2 s jump bursts.
3. **Logic branch (before the e‑stop), 5 A fuse.** Feeds the computers so they stay alive when the e‑stop is pressed. You can still see what happened.
4. **E‑stop (mushroom switch, 2 poles).** Pole 1 cuts the motor bus. Pole 2 opens a sense wire to Teensy pin 32, so the software knows too and sets torque to zero.
5. **Power distribution board (PDB).** Splits the motor bus into six XT30 outputs with 10 A fuses (16 AWG wire). It also carries:
   * **1000 µF low‑ESR capacitor**: a local "reservoir" for sudden current demands;
   * **TVS diode (SMBJ28A)**: when the robot brakes hard or lands, the motors act as generators and push current back. The voltage spikes, and the TVS clamps it before the motor drivers are damaged.
6. **Buck converter #1, 5 V / 5 A → Raspberry Pi 5.** A buck converter steps the voltage down efficiently (~90 %), unlike a linear regulator, which would burn (22 − 5) V × 5 A = 85 W as heat. The Pi needs 5 V at up to 5 A. Because it is fed through its GPIO pins, set `usb_max_current_enable=1`.
7. **Buck converter #2, 5 V / 3 A → sensors and LEDs.**
8. The **Teensy** gets 5 V through its USB cable from the Pi.

**Grounding:** all grounds meet at one star point on the PDB. If the Pi's ground went through a different path than the motors', motor current would flow through the signal grounds and corrupt the CAN and sensor signals.

## 6.4 Talking to the motors: CAN bus
CAN is the bus used in cars. Two wires, **CAN‑H** and **CAN‑L**, carry the signal as a *difference* between them, so noise that hits both wires equally cancels out. That is why it works next to noisy motor cables.

* **Termination**: a 120 Ω resistor at **each end** of the bus absorbs reflections. Missing or extra terminators are the #1 CAN problem.
* **Transceiver**: the Teensy's CAN pins are logic signals (TX/RX). An **SN65HVD230** chip turns them into the differential bus signal. It runs on 3.3 V, which matches the Teensy.
* **Messages**: each frame has an **ID** (who it's for) and up to 8 data bytes. Hip motors listen on IDs 1–4 and answer on 0x11–0x14. Wheel motors use 0x141/0x142.
* **Bus load**: at 1 Mbit/s an 8‑byte frame takes ~0.13 ms. Each millisecond every motor needs one command and one reply. Four frames per bus = 0.52 ms = 52 % load. One bus for all six motors would need 1.56 ms, which doesn't fit in 1 ms. That is why BOLT uses **three buses** (left hips, right hips, wheels). The Teensy 4.1 has exactly three CAN controllers.

## 6.5 The IMU: SPI
The ICM‑42688‑P measures rotation rates (gyro) and acceleration. **SPI** is a fast synchronous bus with four wires: clock (SCK), data out (MOSI), data in (MISO) and chip select (CS). The Teensy pulls CS low, clocks out a register address with the read bit set (`0x1D | 0x80`), and clocks in 14 bytes: temperature plus 3 accelerations plus 3 rotation rates, 16 bits each. At 10 MHz that takes ~12 µs, so reading it every millisecond is easy.

Scaling: ±16 g range → 2048 counts per g; ±2000 °/s → 16.4 counts per °/s.

## 6.6 Pi ↔ Teensy: USB serial
The Teensy appears as `/dev/ttyACM0` on the Pi. The two exchange small binary frames (chapter 7.3): commands at 50 Hz, telemetry at 100 Hz. The same cable powers the Teensy and lets the Pi re‑flash it, so no extra wires are needed.

## 6.7 Sensors
* **Ultrasonic (RCWL‑1601).** A 10 µs pulse on TRIG makes it chirp at 40 kHz. ECHO stays high until the echo returns. Distance = time × 343 m/s ÷ 2 (there and back) = **0.1715 mm per µs**. The Teensy measures the echo with interrupts, firing one sensor every 30 ms so they don't hear each other. The RCWL‑1601 is used instead of the classic HC‑SR04 because **its echo output is 3.3 V**. The Teensy 4.1 is *not* 5 V tolerant.
* **Sharp GP2Y0A21 IR distance (10–80 cm).** It sends an infrared beam and measures the angle of the reflection. The output is an analog voltage (higher = closer, about `d[cm] ≈ 29.99 · V^-1.173`). It can reach 3.1 V, so a **voltage divider** (10 kΩ + 20 kΩ, ratio 2/3) keeps it below 2.1 V for the 3.3 V ADC. Two of them look down‑forward from the chin: if the floor "disappears" (reading jumps beyond the expected 0.27 m), there's a drop‑off ahead.
* **Battery voltage.** Divider 100 kΩ / 6.8 kΩ: 25.2 V × 6.8/106.8 = 1.60 V at the ADC pin, safely below 3.3 V. The firmware multiplies back by 15.7.
* **GPS (u‑blox M10).** Sends text lines over UART (serial, 115200 baud), for example `$GPGGA,123519,4807.038,N,01131.000,E,1,08,0.9,545.4,M,…*47`. That is time, latitude, longitude, fix quality, satellites, accuracy and altitude. `gps.py` checks the checksum after `*` and decodes it.
* **Compass (IST8310).** On I²C, a 2‑wire bus (SDA data, SCL clock) where each chip has an address (0x0E). Optional here.
* **Cameras.** MIPI‑CSI ribbon cables go straight into the Pi 5's two camera ports. That is fast enough for HD video without loading the CPU.

## 6.8 Outputs
* **LED eyes (WS2812B).** Each LED has a tiny controller. A single data wire carries 24 bits per LED (green, red, blue) at 800 kHz, and each LED keeps its 24 bits and passes the rest on. The Teensy library uses a hardware serial port with DMA, so it costs no CPU time. A 330 Ω resistor in the data line protects against ringing. *Note:* these LEDs officially want a 5 V data signal (≥ 3.5 V); 3.3 V usually works. If the eyes flicker, add a 74AHCT125 level shifter.
* **Headlights and IR illuminators.** The Teensy can't supply 300 mA, so it switches an **AO3400 MOSFET** (a transistor that acts like a switch, fully on at 2.5 V gate). **PWM** turns it on and off thousands of times a second; the fraction of on‑time sets the brightness. The 100 Ω gate resistor limits switching current; the 10 kΩ pull‑down keeps the light off while the Teensy boots. A 1 W white LED from 5 V needs a series resistor of about (5 − 3.2) V / 0.3 A ≈ 6 Ω (1 W), or a small constant‑current driver.
* **Buzzer** on a PWM pin (beeps at startup and on errors).

## 6.9 Safety layers
| Layer | What it catches |
|---|---|
| hardware e‑stop | everything; physically cuts motor power |
| motor CAN timeout (50 ms) | Teensy crashed or cable unplugged: motors go limp on their own |
| Teensy watchdog (100 ms) | the control loop hangs: the Teensy resets |
| command timeout (300 ms) | Pi or Wi‑Fi died: the robot stops and keeps balancing |
| fall detection | tipped past 49° pitch / 43° roll: torque off, so it doesn't thrash on the floor |
| battery monitor | below 21.0 V: limited to 0.5 m/s; below 19.8 V: motors off (protects the LiPo) |
| calibration check | never enables motors with unknown leg zero positions |

## 6.10 Assembly order for the wiring (beginner tips)
1. Build and test the **power path without motors**: battery → fuse → e‑stop → PDB. Measure voltages with a multimeter at every stage.
2. Add the 5 V bucks, **adjust and measure 5.0–5.1 V before** connecting the Pi.
3. Connect the Teensy to a PC first. Flash the firmware and watch the serial output.
4. Add CAN bus 3 (wheels) with one motor, test, then add the second, then the hip buses.
5. Check termination with the battery **unplugged**: measure between CAN‑H and CAN‑L, expect **60 Ω** (two 120 Ω in parallel).
6. LiPo safety: charge in a fire‑safe bag with a balance charger, never below 3.3 V per cell, unplug for storage.

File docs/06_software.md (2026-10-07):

# 6 · Software — control code, brain and controller app

```
 phone app (PWA) ──Wi‑Fi/WebSocket──┐            Mission Planner ──UDP 14550 MAVLink──┐
                                     ▼                                                ▼
 ┌────────────────────── Raspberry Pi 5 : companion/robot_brain (Python, 20 Hz) ───────────────────────┐
 │ app_server.py   behaviors.py (Brain: modes, actions, safety reflexes)   mission/mavlink_vehicle.py   │
 │ perception/line_follower.py  perception/obstacles.py  navigation/planner.py (A*, road graph, halt)   │
 │ gps.py (NMEA, ENU)  io_real.py (Teensy link, Picamera2 x2, GPS)                                      │
 └───────────────────────────────── link.py  ⇅ USB, 50 Hz cmd / 100 Hz telemetry ──────────────────────┘
 ┌──────────────────── Teensy 4.1 : firmware/ (C++, 1 kHz) ───────────────────────────────────────────┐
 │ main.cpp: IMU → Mahony → bolt_core::Controller → torques → 3 CAN buses; sensors; eyes; watchdogs     │
 │ lib/bolt_core: five_bar.h, bolt_controller.cpp  (← the SAME code runs in the MuJoCo simulator)       │
 └─────────────── CAN1/CAN2: 4 × DM‑J4310 hips ─────────── CAN3: 2 × MF9025 wheels ────────────────────┘
```

## 6.1 Real‑time controller (`firmware/lib/bolt_core`)

Every millisecond:

1. **Leg kinematics** (`five_bar.h`): from the two thigh angles φ1, φ4 compute the foot position, the *virtual leg* (length L, angle θb relative to the body) and the Jacobian J = ∂(L, θb)/∂(φ1, φ4).
2. **State estimate**: world leg angle θ = θb − pitch, wheel ground speed from the wheel motor speed corrected for the shin's own rotation, odometry s.
3. **Balance — gain‑scheduled LQR.** State `x = [θ, θ̇, s − s_ref, ṡ − v_ref, pitch − pitch_ref, pitch_rate]`, input `u = [wheel torque, hip torque]`, `u = u_eq − K(L)·x`. K is solved offline for 14 leg lengths on the linearised wheel‑leg‑body model whose masses/inertias are measured from the MuJoCo model (`sim/lqr_design.py`), and fitted with cubic polynomials in L → `robot_config_generated.h`. `u_eq` / θ_eq hold a commanded body pitch (bow / lean back) statically.
4. **Legs — virtual model control.** Per leg a spring‑damper on L (+ gravity feed‑forward), roll PD+I (left/right legs differentially → level body on side slopes, or a commanded lean), turn compensation (outer leg pushes more in curves), and a sync term that keeps both legs at the same angle. Leg force F and leg torque Tp are mapped to the two hip motors with `τ = Jᵀ [F, Tp]` (torque‑limited).
5. **Yaw**: PI on yaw rate → differential wheel torque.
6. **Mode / state machine**

| State | What happens |
|---|---|
| BALANCE | normal driving; position reference integrates the speed command (holds position on slopes), re‑anchored when you start/reverse (no catch‑up surges) |
| CROUCH | lower to the crouch length; if a step edge distance was given, roll on and **fire exactly when** `remaining ≤ v·(t_thrust + t_clear) + R + margin` |
| THRUST | constant leg force sized from energy so the take‑off speed gives the requested clearance (accelerate in the first 40 % of the stroke, then coast); wheel torque limited; a feed‑forward hip torque cancels the moment of the leg force about the body COM |
| FLIGHT | tuck legs, hold them straight down in the body frame (no body spin); jump‑over mode extends after apex for a soft landing; touchdown = leg gets compressed while armed |
| LAND | ramp back to ride height with double damping, balance law on |
| AIRBORNE | picked up / wheels unloaded → wheels stop, legs hold |
| FALLEN | tilt beyond limits → torque off (limp, protects gears and electronics) |
| RECOVER | experimental self‑righting (not working yet, see limits) |

Jump planning: the wheel clearance at the apex is the COM rise plus the leg retraction seen by the wheel, so the requested height `h` gives the COM rise `h_com = h + clearance − (L_takeoff − L_retract)·m_body/m_total` → take‑off speed `v = √(2 g h_com)·m_total/m_body` → thrust force. In simulation the planned and achieved clearances agree within ~1 cm up to the motor limit (~22 cm).

### Safety layers
Motor CAN timeout (50 ms) · Teensy watchdog (100 ms) · Pi command timeout 300 ms → stop & hold · e‑stop (hardware power cut + sense pin) · fall detection → limp · battery low → 0.5 m/s cap, critical → sit & off · uncalibrated → motors never enabled.

## 6.2 Build and flash the firmware
```bash
cd firmware
pio run -t upload              # PlatformIO (VS Code extension or CLI), board teensy41
# or from the Raspberry Pi over the existing USB cable:
pio run && teensy_loader_cli --mcu=TEENSY41 -w -v .pio/build/teensy41/firmware.hex
```
`firmware/tools/check_build.sh` compiles and links the firmware with plain `arm-none-eabi-g++` against the Teensy core sources (no PlatformIO needed) — that's how this repository was verified (62 KB code).

## 6.3 Companion brain (`companion/`)
```bash
cd companion
python3 -m robot_brain.main --config config.yaml       # or: sudo systemctl start bolt
python3 -m pytest -q tests                             # link byte-compat with the firmware, GPS, A*, re-routing
```
**Modes** (app "Auto" tab or Mission Planner): `MANUAL`, `LINE` (colour line following), `EXPLORE` (wander & avoid), `MISSION` (= Mission Planner AUTO), `GUIDED` (fly‑to‑here), `RTL`, `HOLD`, `IDLE`.

**Actions** (app buttons / mission items): `jump` (in place or while moving, height slider), `hop` (over an obstacle ahead), `step_up` (onto a curb/step), `stairs` (repeated step‑ups, experimental), `dodge_left/right`, `sit`, `stand`; posture: height, crawl, tilt (pitch), lean (roll).

`hop` / `step_up` locate the edge with the **front camera** (`perception/step_detector.py`: lowest straight horizontal edges + ground‑plane geometry, riser top/base matched using the step height from the slider; ≤ 2 cm error at 0.5–0.9 m in simulation). The sonar can't do this: it sits 0.33 m high and its beam passes over low steps. Procedure: stop‑and‑measure (creeping if needed) until the edge is 0.5–0.75 m away → back up 1.6 m by odometry → run up at 1 m/s → hand the remaining distance to the controller at 0.9 m, which times the take‑off itself. **Experimental**: start the action with BOLT 0.5–0.8 m in front of the step, facing it; it refuses with a message rather than guessing when it can't locate the edge.

**Line following** (`perception/line_follower.py`): HSV mask of the lower image (red, orange, yellow, green, blue, black, white or custom ranges) → line offset + heading from two bands → PD yaw‑rate, speed reduced in curves. Obstacle on the line → stop, wait 5 s, then HALT. Line lost → search for 4 s, then HALT. When the image floor is dark the brain switches on the headlight and the 850 nm IR illuminator automatically.

**Obstacles & halting** (`navigation/planner.py`): sonar returns go into a rolling 40 × 40 m log‑odds grid (10 cm). Every 0.5 s an 8‑connected A* on the inflated grid plans the detour, pure pursuit follows it, a reflex stops at 0.3 m. If A* finds no route: turn on the spot to scan (sonars only see forward); still nothing after a full turn → on a mission, mark that road segment blocked and re‑route over the road graph; no route at all → **HALT** + status text to the app and Mission Planner.

**GPS missions** (`mission/mavlink_vehicle.py` + `behaviors.py`): BOLT is a MAVLink *Rover* (heartbeat, position, attitude, GPS, battery, mission protocol, arm, mode changes, fly‑to‑here, a few params). Between waypoints it plans the **shortest route on the road graph (A* with haversine heuristic)**. Pose = wheel odometry + IMU yaw fused with GPS (complementary filter; heading corrected from the GPS course when driving straight).

## 6.4 Controller app (`app/`)
A Progressive Web App served by the robot: open `http://bolt.local:8080` on the phone → "Add to Home screen" → it runs full‑screen like a native app (Android & iOS), works offline on the robot's own Wi‑Fi.

* **Drive tab**: joystick (expo curve), max‑speed slider, **Jump / Hop over / Step up / Stairs / Dodge ◀ ▶ / Crawl / Stand‑Sit**, sliders for height, tilt (pitch), lean (roll), jump height; **Level** button.
* **Auto tab**: Manual / Hold / Explore & avoid / Return home; line‑following colour picker + speed; sonar radar.
* **Mission tab**: add the current position / typed lat‑lon / jump steps, mini‑map with the planned A* route, start / pause.
* **Setup tab**: auto lights, headlight & IR sliders, eye expressions, robot address, sit, release e‑stop.
* Always visible: link dot, state, mode, battery, big **STOP**, live front/rear camera with artificial horizon, alerts as toasts. Keyboard on desktop: W/A/S/D, Space = jump, C = crawl, X = stop.

Protocol (JSON over `/ws`) is documented at the top of `companion/robot_brain/app_server.py`; the app was tested in headless Chromium against the simulated robot (drive, jump state sequence, crawl, waypoints, e‑stop, no JS errors).

## 6.5 Simulation workflow (`sim/`)
```bash
pip install mujoco numpy scipy matplotlib trimesh manifold3d opencv-python-headless pymavlink aiohttp pyyaml
python3 cad/build_parts.py            # CAD -> STL + mass report (feeds the sim)
python3 sim/lqr_design.py             # gains for V1..V3, writes the firmware header
python3 sim/test_suite.py V1 V2 V3    # 15 requirement tests per design -> sim/results/*.json
python3 sim/companion_sim.py --demo all   # brain-in-the-loop: line, obstacles/halt, Mission Planner mission
python3 sim/companion_sim.py --demo app   # drive the simulated robot from the real app at http://localhost:8080
python3 sim/make_report.py            # figures for docs/04
```

## 6.6 Bring‑up checklist (real robot)
1. Calibrate and check signs (§3.8). 2. `bolt_cli.py balance` held by hand, then let go. 3. App: drive slowly, then height/tilt/lean sliders. 4. Small jumps (0.05 m) on grass/carpet before anything else. 5. Step‑ups with foam blocks before hard curbs. 6. Line following on tape, then missions in an empty car park.

**Tuning knobs**: LQR weights `Q_DIAG`, `R_DIAG` in `sim/lqr_design.py` (more weight on pitch = stiffer body; more on s/ṡ = tighter position) → regenerate the header; leg spring/damper `kp_leg/kd_leg`; roll `kp/kd/ki_roll`; yaw `kp/ki_yaw`; jump `thrust_force`, `jump_clearance`, `JUMP_EDGE_MARGIN`. Change them in the sim first, run the suite, then flash.

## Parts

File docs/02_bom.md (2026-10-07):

# 2 · Bill of materials

Prices are rough 2026 street prices (USD) for orientation only.

## Actuation & power
| Qty | Part | Notes | ~USD |
|---|---|---|---|
| 4 | **DM‑J4310‑2EC** quasi‑direct‑drive actuator (Damiao) | hips; 10:1, 3 Nm cont. / 7 Nm peak, CAN, MIT mode, dual encoder | 4 × 100 |
| 2 | **LK‑TECH MF9025v2** hub motor with driver (CAN version) | wheels; direct drive, ~4 Nm peak | 2 × 140 |
| 1 | 6S 5000 mAh 50C LiPo, XT90‑S | e.g. CNHL / Tattu; fits 155 × 52 × 46 mm | 70 |
| 1 | XT90‑S anti‑spark pair, 40 A blade fuse + holder, 5 A fuse | | 10 |
| 1 | Mushroom e‑stop, 2‑pole, ≥ 32 A DC | pole 1 motor bus, pole 2 sense loop | 15 |
| 1 | Small PDB / bus bar, 6 × XT30, 6 × 10 A fuses | or a 3D‑printed bus bar + inline fuses | 20 |
| 1 | 1000 µF 50 V low‑ESR capacitor + SMBJ28A TVS | motor bus protection | 3 |
| 1 | 5 V 5 A buck (Pololu D36V50F5 or Matek BEC 12S‑PRO) | Raspberry Pi 5 | 25 |
| 1 | 5 V 3 A buck | sensors + LEDs | 8 |
| — | Silicone wire 12 / 16 / 20 AWG, XT30 pigtails, CAN twisted pair, JST‑GH | | 30 |

## Computing & sensors
| Qty | Part | Notes | ~USD |
|---|---|---|---|
| 1 | **Teensy 4.1** | real‑time controller, 3 × CAN | 32 |
| 3 | SN65HVD230 CAN transceiver breakout | one per bus | 3 × 3 |
| 1 | ICM‑42688‑P IMU breakout (SPI) | | 12 |
| 1 | **Raspberry Pi 5, 8 GB** + active cooler + 64 GB A2 microSD | brain | 95 |
| 2 | **Arducam IMX219 NoIR with M12 220° fisheye lens**, Pi 5 FPC cables (22‑pin) | front + rear | 2 × 35 |
| 1 | **Holybro M10 GPS** (u‑blox M10 + IST8310 compass) | the usual Pixhawk/Mission Planner puck | 40 |
| 4 | RCWL‑1601 ultrasonic (3.3 V HC‑SR04) | | 4 × 2 |
| 2 | Sharp GP2Y0A21YK0F IR distance (10–80 cm) | drop‑off sensors | 2 × 8 |
| 2 | WS2812B 12‑LED ring (37 mm) | eyes | 2 × 3 |
| 2 + 4 | 1 W white LED + 850 nm IR LEDs, 2 × AO3400 MOSFET | headlights / night vision | 8 |
| 1 | Piezo buzzer, resistors (100k/6.8k, 10k/20k, 330R, 100R, 10k) | | 3 |

## Mechanical hardware
| Qty | Part | Use |
|---|---|---|
| 12 | 608‑2RS bearing (8 × 22 × 7) | knees (4) and foot joints (2), spares |
| 6 | M8 × 30 shoulder bolt + nyloc | knee / foot pins |
| ~60 | M3 heat‑set inserts (M3 × 5.7) | frame, sled, shell bosses |
| ~80 | M3 SHCS (8–16 mm), M4 × 12 (wheel stators) | |
| 16 | M2.5 × 6 + standoffs | Pi 5, cameras |
| 14 | 6 × 3 mm N52 disc magnets | shell, lids |
| 4 | Rubber grommets (M2.5) | Raspberry Pi damping (NOT the IMU) |
| 2 | M3 thumb screws | clamp the electronics sled |
| 1 | 20 mm Velcro strap | battery |

## Filament (≈ 2.5 kg printed)
| Material | Parts | ≈ g |
|---|---|---|
| PA‑CF (or PETG‑CF) | side plates, floor, top frame, thighs, shins | 1 050 |
| PETG‑CF | belly pan, sled, wheel rims | 540 |
| PETG | shell halves, payload bay + lid, cap, tray, brackets | 520 |
| TPU 95A | tyres, bumpers | 410 |
| clear PETG | face visor (smoke‑tinted) | 15 |

**Total ≈ USD 1 250** (motors are ~60 %). A budget variant with hobby servos for the legs cannot jump and is not covered here.

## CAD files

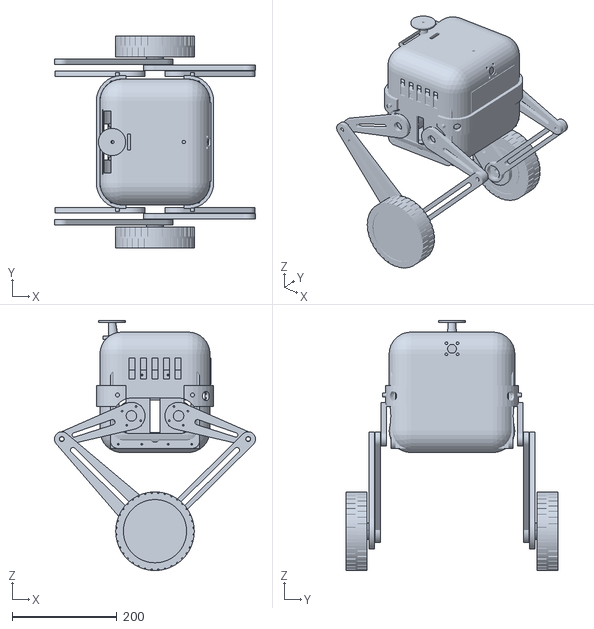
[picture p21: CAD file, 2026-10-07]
cad/assembly_nominal_pose.stl
383.6 x 404.0 x 477.0

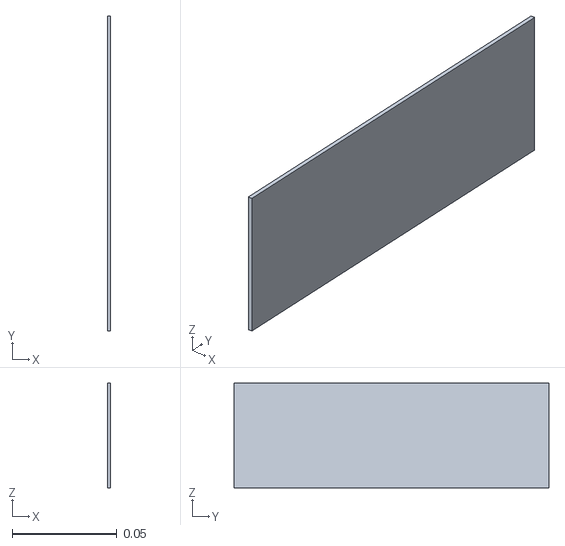
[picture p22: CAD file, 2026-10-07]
cad/assembly/visor.stl
0.0015 x 0.15 x 0.05

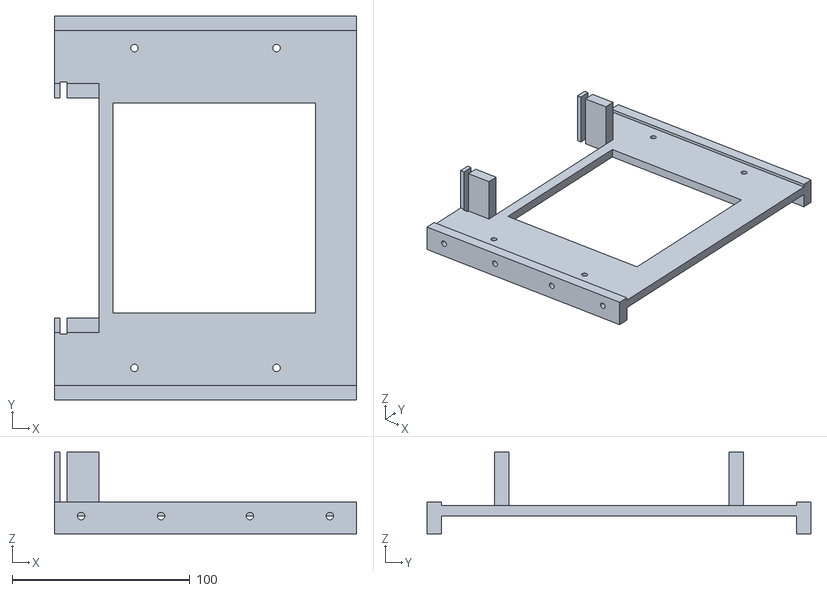
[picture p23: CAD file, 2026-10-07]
cad/stl/top_frame.stl
170.0 x 216.0 x 46.0

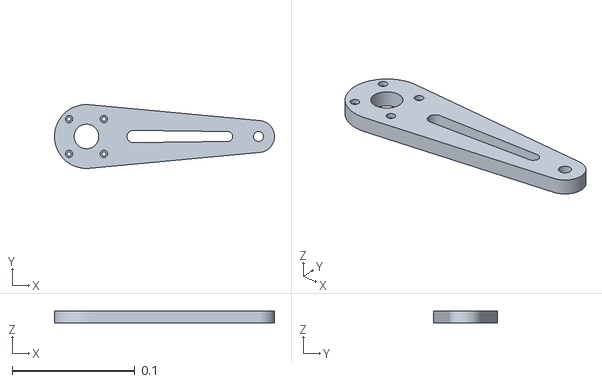
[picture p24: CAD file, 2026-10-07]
cad/assembly/thigh.stl
0.179 x 0.052 x 0.01

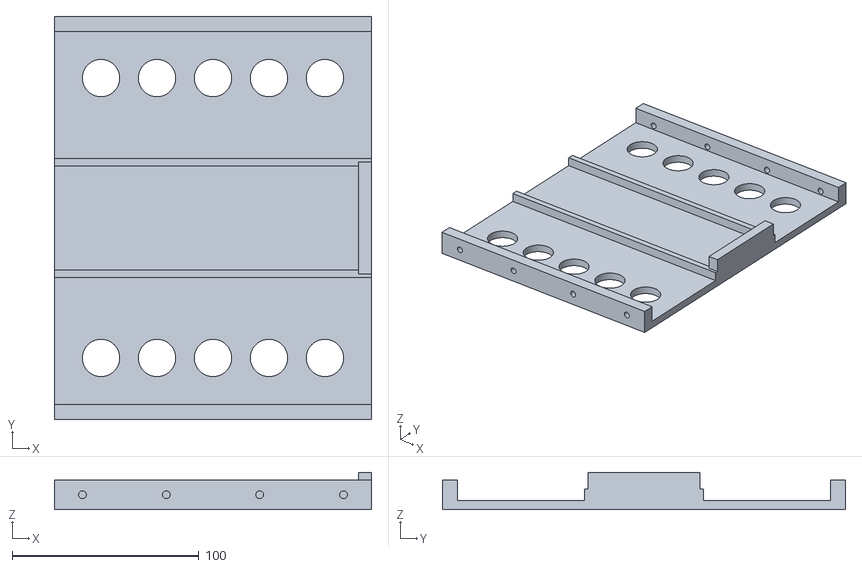
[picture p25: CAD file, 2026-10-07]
cad/stl/floor_plate.stl
170.0 x 216.0 x 20.0

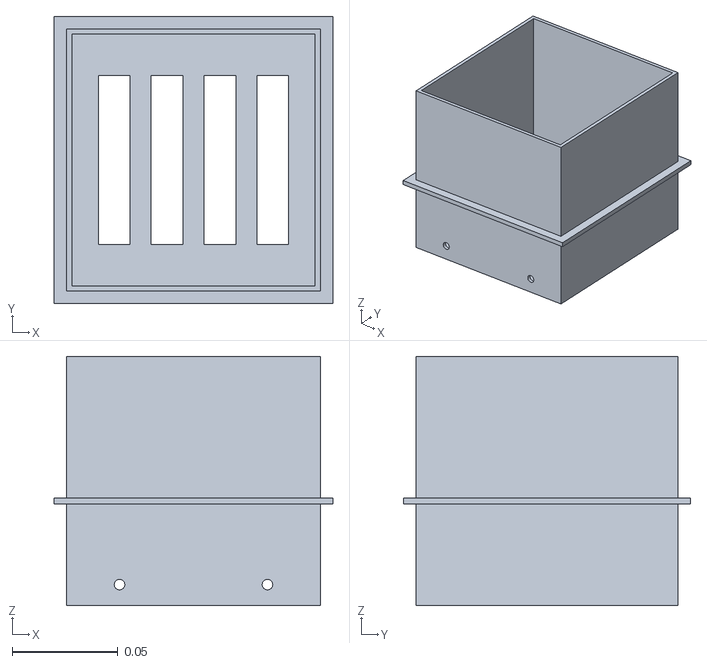
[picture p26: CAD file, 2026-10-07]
cad/assembly/payload_bay.stl
0.132 x 0.136 x 0.118

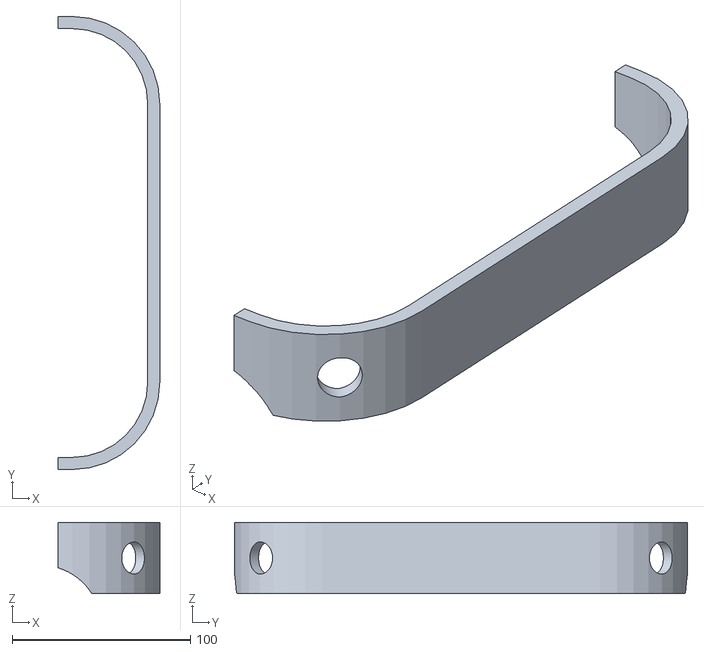
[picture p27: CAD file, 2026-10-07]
cad/stl/bumper_front.stl
57.0 x 254.0 x 40.0

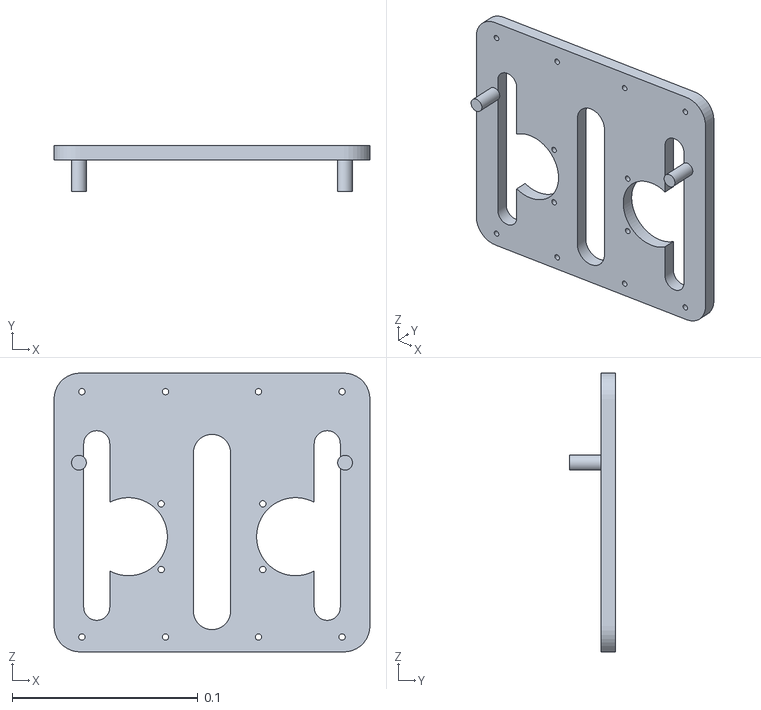
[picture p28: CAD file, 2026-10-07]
cad/assembly/side_plate_R.stl
0.17 x 0.025 x 0.15

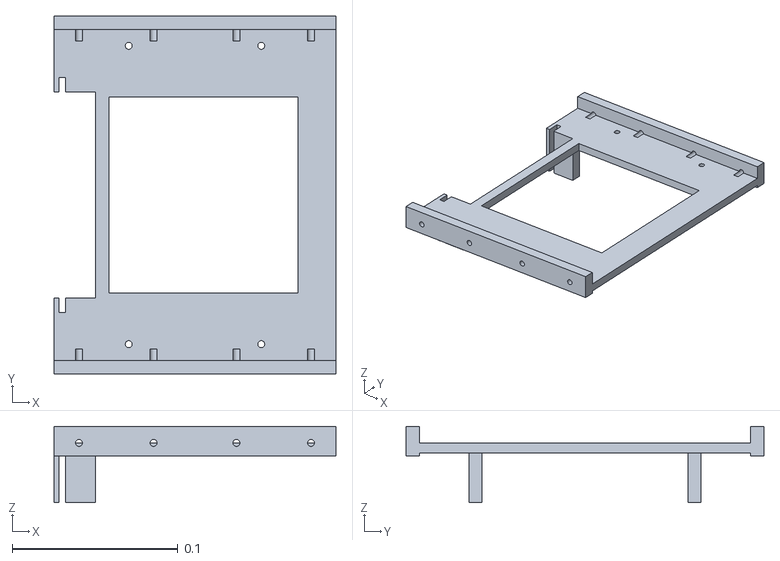
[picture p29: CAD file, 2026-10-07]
cad/assembly/top_frame.stl
0.17 x 0.216 x 0.046

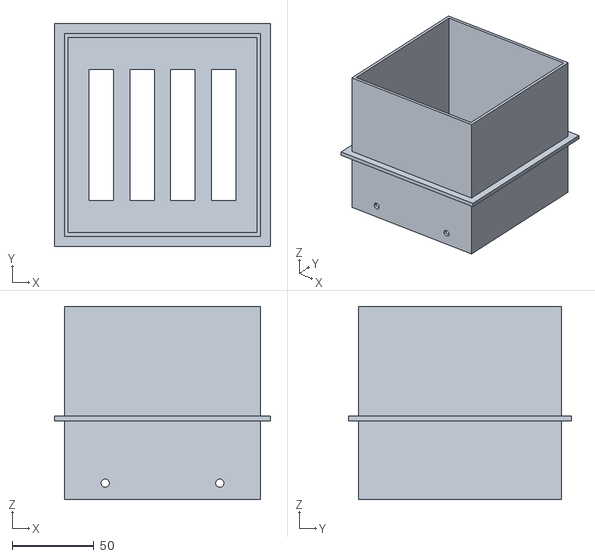
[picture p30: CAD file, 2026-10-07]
cad/stl/payload_bay.stl
132.0 x 136.0 x 118.0

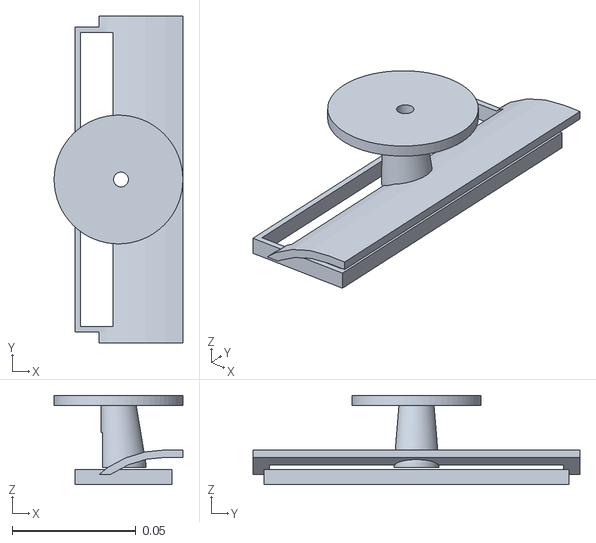
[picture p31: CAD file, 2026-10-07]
cad/assembly/electronics_cap.stl
0.052 x 0.132 x 0.036

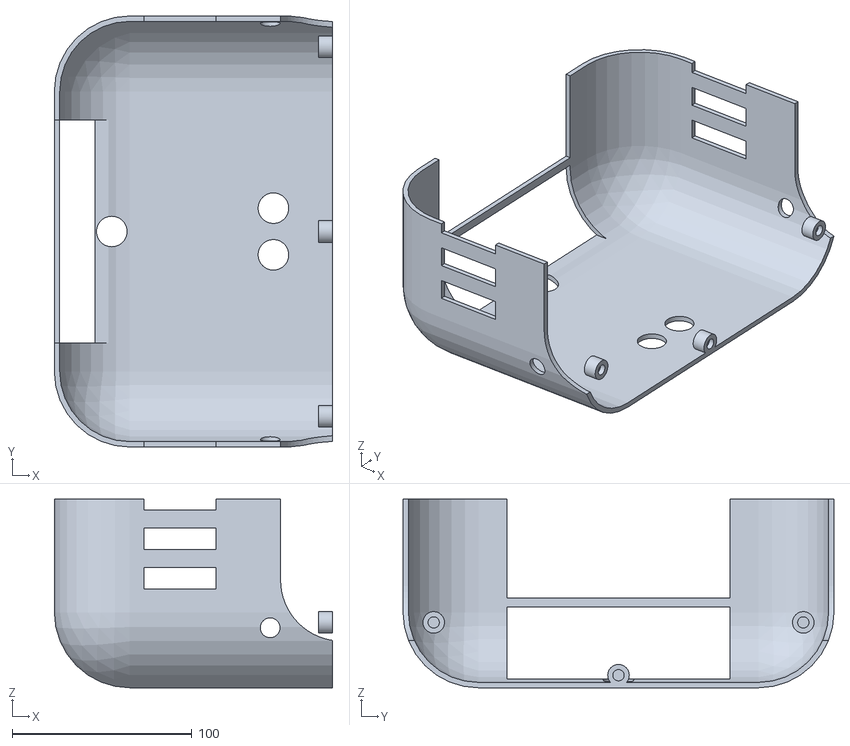
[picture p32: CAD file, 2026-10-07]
cad/stl/shell_rear.stl
155.0 x 240.0 x 105.0

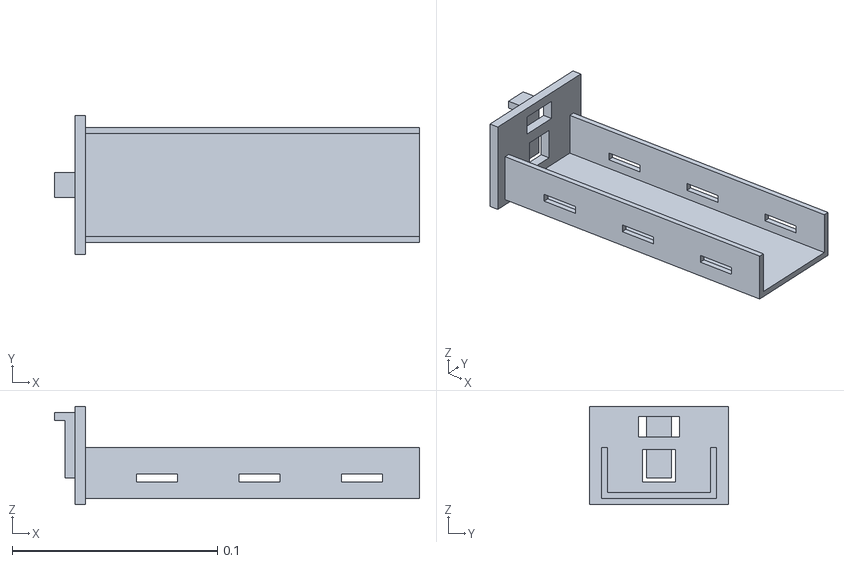
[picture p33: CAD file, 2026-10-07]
cad/assembly/battery_tray.stl
0.178 x 0.068 x 0.048

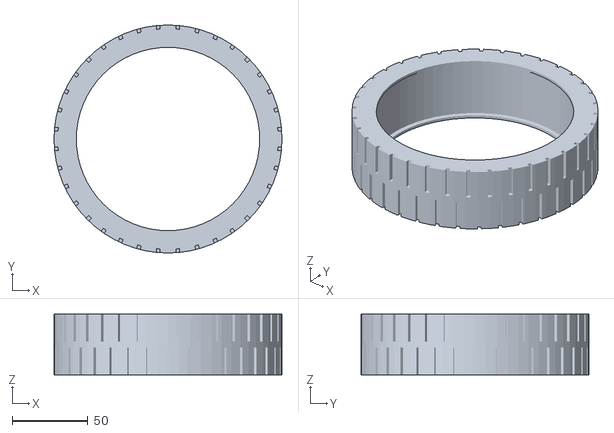
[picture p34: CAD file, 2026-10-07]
cad/stl/tyre.stl
150.0 x 150.0 x 40.0

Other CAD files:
cad/stl/bumper_rear.stl
cad/assembly/bumper_rear.stl
cad/stl/visor.stl
cad/assembly/wheel_rim.stl
cad/assembly/belly_pan.stl
cad/assembly/bumper_front.stl
cad/assembly/electronics_sled.stl
cad/assembly/floor_plate.stl
cad/assembly/payload_lid.stl
cad/assembly/shell_front.stl
cad/assembly/shell_rear.stl
cad/assembly/shin_front.stl
cad/assembly/shin_rear.stl
cad/assembly/side_plate_L.stl
cad/assembly/tyre.stl
cad/stl/battery_tray.stl
cad/stl/belly_pan.stl
cad/stl/camera_mount.stl
cad/stl/electronics_cap.stl
cad/stl/electronics_sled.stl
cad/stl/payload_lid.stl
cad/stl/shell_front.stl
cad/stl/shin_front.stl
cad/stl/shin_rear.stl
cad/stl/side_plate_L.stl
cad/stl/side_plate_R.stl
cad/stl/sonar_bracket.stl
cad/stl/thigh.stl
cad/stl/wheel_rim.stl

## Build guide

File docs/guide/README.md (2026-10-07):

# The BOLT guide — how this robot was designed, explained from zero

This guide is for someone who has **never built a robot like this**. It explains *why* every decision was made, the physics behind it, how the mechanism moves, how the simulation was set up, how the design was improved step by step, how the electronics work and how every piece of code works. You don't need to read the code first: each chapter points to the exact files when you're ready.

The reference documents in `docs/01…06` are the short "what and how to build it" version. This guide is the long "why and how does it work" version.

| # | Chapter | You will learn |
|---|---|---|
| 1 | [How the project was made](01_how_it_was_made.md) | the whole process from a wish list to a tested design — the order to do things in, and why |
| 2 | [The physics](02_physics.md) | why a two‑wheeler falls, how it balances, the maths of LQR in plain words, slopes, turning, jumping, motors |
| 3 | [The mechanism and linkages](03_mechanism.md) | the 5‑bar leg joint by joint, forward/inverse kinematics with real numbers, how motor torque becomes leg force, structure and materials |
| 4 | [The CAD](04_cad.md) | how the parts are generated by code, how each part is shaped and why, print orientation, mass and centre of mass |
| 5 | [The simulation and the iterations](05_simulation.md) | MuJoCo basics, how the robot model is built, how the controller was designed from it, the 15 tests, the V1→V3 story and every bug the tests caught |
| 6 | [The electronics](06_electronics.md) | power, batteries, fuses, CAN bus, SPI, USB, I²C, PWM, voltage dividers — with the actual numbers used here |
| 7 | [The code](07_code.md) | a walkthrough of the firmware, the controller, the Raspberry Pi brain, the app and the tests, plus "recipes" for changing things |
| 8 | [Glossary and learning path](08_glossary.md) | every term used in this repository, and what to study in which order |

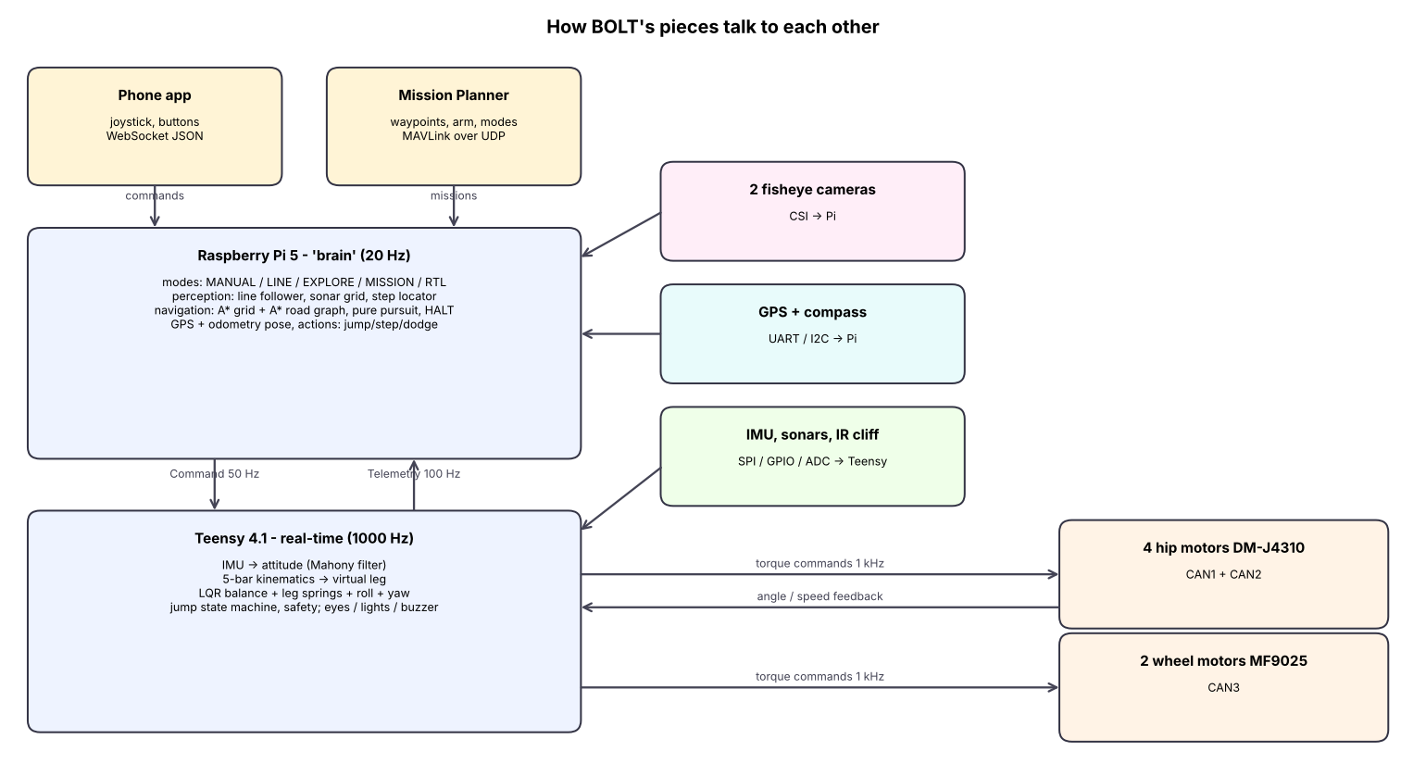
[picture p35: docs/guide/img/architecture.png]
architecture


All figures in `docs/guide/img` are regenerated by `python3 docs/guide/make_figures.py`.

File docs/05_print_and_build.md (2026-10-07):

# 5 · Printing and assembly

All printable parts are generated by `python3 cad/build_parts.py` → `cad/stl/*.stl` (already in print orientation, watertight). The script is parametric: change `design/params.py` (leg lengths, wheel size, body size) or the interface constants at the top of `cad/build_parts.py` (motor bolt circles, bearing size, magnets) and re‑run. `cad/assembly_nominal_pose.stl` is the whole robot standing, for a quick look in any slicer/viewer.

> **Check before printing**: the motor bolt patterns (`HIP_PCD`, `HIP_STATOR_PCD`, `WHEEL_STATOR_PCD`, `WHEEL_ROTOR_PCD`) against the drawings of the motors you received.

Printer: 256 × 256 mm bed (Bambu P1S/X1, Prusa Core One, Voron 250 …), hardened nozzle for CF filaments. 0.2 mm layers unless noted.

## 5.1 Parts list

| STL | Qty | Material | Print notes | ≈ g each |
|---|---|---|---|---|
| side_plate_L / _R | 1 + 1 | PA‑CF (PETG‑CF ok) | flat, 6 walls, 40 % gyroid — **structural**, carries the hip motors and the calibration end‑stop pegs | 119 |
| floor_plate | 1 | PA‑CF | flat, 5 walls, 40 % — battery rails | 170 |
| top_frame | 1 | PA‑CF | upside down, 5 walls, 35 % — sled guides, roof‑rack inserts | 130 |
| thigh | 4 | PA‑CF | flat, **100 % infill or 8 walls** (jump loads) | 45 |
| shin_front | 2 | PA‑CF | flat, **diagonal** on the bed, 8 walls, 50 % | 43 |
| shin_rear | 2 | PA‑CF | flat, boss down (supports), diagonal, 8 walls, 50 % | 103 |
| wheel_rim | 2 | PETG‑CF | flat, 6 walls, 40 % | 142 |
| tyre | 2 | TPU 95A (85A = more grip) | 4 walls, 20 % gyroid, 25 mm/s | 146 |
| belly_pan | 1 | PETG‑CF | split face on bed, 4 walls, 25 % | 197 |
| shell_front / shell_rear | 1 + 1 | PETG (your colour — yellow in the renders) | split face on bed, 3 walls, 15 %, tree supports for the eye/camera holes | 128 / 124 |
| visor | 1 | smoke / clear PETG | 100 %, 0.12 mm — glued over the face opening | 14 |
| bumper_front / _rear | 1 + 1 | TPU 95A (red "cheeks") | 3 walls, 25 % | 58 / 60 |
| payload_bay | 1 | PETG | open side up, 3 walls, 20 % | 116 |
| payload_lid | 1 | PETG | outer face down (textured PEI) | 39 |
| electronics_sled | 1 | PETG‑CF | flat, 4 walls, 30 % | 56 |
| electronics_cap | 1 | PETG | upright, supports under the GPS seat | 19 |
| battery_tray | 1 | PETG | flat, 4 walls, 30 % | 45 |
| camera_mount | 2 | PETG | flat | 4 |
| sonar_bracket | 4 | PETG | flat | 3 |

≈ 2.5 kg of filament, ~55 h of printing.

PA‑CF: dry it (80 °C, 6 h) and anneal structural parts after printing (80–90 °C, 2 h) for stiffness. PETG‑CF is a fine substitute at ~20 % lower stiffness.

## 5.2 Hardware prep
* Heat‑set inserts (M3): floor plate and top frame side edges (8 each), top frame roof‑rack (4), shell magnet bosses → magnets instead (glue, check polarity so front/rear shells attract the belly pan).
* Press 608‑2RS bearings into both shins (knee end) and the front shin foot end; the M8 shoulder bolt is the pin.

## 5.3 Assembly order
1. **Chassis box**: bolt the 4 hip motors (DM‑J4310) to the inner faces of the side plates (stator bolt circle), output through the plate. Join the side plates with the floor plate and top frame (M3 into inserts). The hip motor outputs now stick out on both sides.
2. **Legs**: thighs onto the motor output flanges (4 × M3, counter‑bored). Front shin on the front thigh knee pin, rear shin on the rear thigh knee pin; the front shin's foot ring slides over the rear shin's axle boss (the two shins share the wheel axis). Bolt the MF9025 stator to the rear shin foot (M4), then the wheel rim onto the motor's output face (6 × M3), then stretch the TPU tyre over the rim lips.
3. **Wiring**: PDB + e‑stop + fuses in the belly area beside the battery rails; motor XT30s and CAN daisy chains along the side plates; CAN termination at the last motor of each bus.
4. **Electronics sled**: Pi 5 (grommets) on the front face, Teensy carrier (IMU hard‑mounted) + bucks on the back face; cameras and GPS run to the sled connector. Slide the sled into the top‑frame guides, plug the 12‑pin + XT30, clamp with the two thumb screws.
5. **Battery tray**: strap the 6S pack, slide in from the rear until the latch clicks.
6. **Sensors**: sonars into the face (mouth + cheeks) and rear brackets, Sharp sensors in the chin, cameras on their tilted mounts behind the forehead/rear holes, eyes (WS2812 rings) behind the visor.
7. **Shells**: belly pan, then front and rear shells (magnets), bumpers (TPU, M3 into the shell bosses), payload bay + lid, electronics cap with the GPS puck.
8. **Calibrate** (§3.8 of [03_electronics_and_settings.md](03_electronics_and_settings.md)): fold the legs onto the end‑stop pegs → `bolt_cli.py calibrate`.

## 5.4 Mechanical checks
* Legs must move freely over the whole range by hand (motors unpowered), thighs must not touch the shell, the end‑stop pegs touch the thighs only in the fully folded pose.
* Wheels: < 0.5 mm wobble; the rim must not touch the motor body (1.5 mm radial gap).
* Total mass on a scale ≈ 6.4 kg without payload. If very different, update the component masses in `design/params.py` and re‑run `python3 sim/lqr_design.py` (gains change with mass!).

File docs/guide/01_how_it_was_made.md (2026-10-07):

# Chapter 1 — How the project was made

This chapter tells the story in the order the work was actually done. If you want to design your own robot, copy the **order**, not just the result: each step produces the numbers the next step needs.

## 1.1 Start from the wish list, turn it into numbers

The request had 12 features (balance on rough and sloped ground, removable electronics, cute and printable, cameras, fast, jumping, tilting/crawling, payload, autonomy without lidar, halting, GPS missions, phone control). A wish like "run fast" can't be designed for; a number can. So the first job was to give every wish a target:

| Wish | Target I used |
|---|---|
| balance on inclined terrain | climb and stand on ≥ 20° ramps, ≥ 12° side slopes |
| rough terrain | ≥ 5 cm bumps at speed |
| run fast without damage | ≥ 2 m/s with torque to spare, survive falls |
| jump steps / obstacles | ≥ 15 cm steps (a normal curb/stair is 15–18 cm) |
| payload | 2 kg |
| tilt / crawl | ≥ ±15° pitch and roll, noticeably lower stance |

These targets became the **pass/fail tests** of the simulation (chapter 5). Writing the tests from the wish list *before* the design is the single most useful habit in this project.

## 1.2 Choose the architecture (the big decision)

Candidates:

1. **Two‑wheeled self‑balancer (Segway style)** — simple, fast, but it cannot jump, cannot crawl lower, and bumps go straight into the body.
2. **Quadruped (four legs)** — handles stairs, but is slow, heavy, needs 12 motors and very hard control.
3. **Wheel‑legged biped** (Boston Dynamics *Handle*, ETH *Ascento*, Direct Drive *Diablo*) — two legs that end in wheels. Wheels give speed and efficiency; legs give suspension, height change, tilt and jumping.

Option 3 covers the most wishes with the fewest motors (6), so BOLT is a wheel‑legged biped.

Next: what kind of leg? Each leg needs **two** controllable things: its length (for height, crawling, jumping, absorbing bumps) and its angle (to keep the wheel under the body on slopes and while accelerating). The common designs:

* a serial leg (hip motor + knee motor on the leg) — the knee motor rides on the leg, making it heavy and slow to swing;
* a **5‑bar parallel linkage** — both motors sit on the body, the leg is just light printed links. Light legs = fast legs = good jumping. This is what BOLT uses (chapter 3).

## 1.3 Pick motors with a back‑of‑the‑envelope calculation

Guess the mass first (motors + battery + electronics + ~2.5 kg of prints ≈ 6–6.5 kg), then check that motors exist that can:

* **Hold the body**: each leg carries about half the body (~21 N). Through the 5‑bar (chapter 3) that needs ~1.8 Nm per hip motor — fine for a motor rated 3 Nm continuous.
* **Jump**: to lift the body 10–15 cm the legs must push several times the weight for a fraction of a second → several Nm peak, **and** turn fast (≈ 10–20 rad/s). That points to "quasi‑direct‑drive" actuators (a strong brushless motor with a small 6–10:1 gearbox) used in small legged robots. The **DM‑J4310‑2EC** (7 Nm peak, ~20 rad/s, CAN bus, 300 g) is a common, affordable choice.
* **Drive and balance**: a hub motor with ~2–4 Nm and a few hundred rpm on a ~15 cm wheel gives 2–2.5 m/s. The **LK MF9025** direct‑drive hub motor fits.

Then the brains: balancing needs a fast, predictable loop (1000 times per second) → a microcontroller (**Teensy 4.1**, 600 MHz, three CAN buses). Vision, maps, Wi‑Fi and the app need a small computer → **Raspberry Pi 5**. Splitting "fast and simple" from "slow and smart" is standard in robotics: if the Pi crashes, the robot still balances.

## 1.4 Write all dimensions in ONE file

`design/params.py` holds every important number: link lengths, wheel size, body size, where each heavy component sits, motor data. **Everything else reads this file** — the CAD, the simulator, the controller design. Change a number once and the whole chain updates. Three versions of the design (V1, V2, V3) live in the same file so the comparison is reproducible.

## 1.5 Kinematics before CAD

Before drawing a single part, `design/kinematics.py` checks that the leg geometry can reach every required length (0.13 m crouched to 0.35 m stretched) without the links locking up. That's 60 lines of trigonometry (chapter 3) and it decides the link lengths: thigh 140 mm, shin 250 mm, hips 90 mm apart.

## 1.6 CAD as code

The parts are generated by a Python script (`cad/build_parts.py`) using constructive solid geometry: boxes, cylinders and spheres are added and subtracted (chapter 4). Advantages for a beginner: the parts can never disagree with `params.py`, and the script also **weighs every part and finds the centre of mass**, which the simulator needs.

## 1.7 Simulate before building

`sim/robot_model.py` turns params + CAD masses into a MuJoCo physics model: body, the two closed 5‑bar legs, wheels with tyre–ground contact. Then:

1. **Design the controller from the model** (`sim/lqr_design.py`): measure the masses/inertias of the model, build the simplified "wheel + leg + body" equations, compute optimal gains with LQR for 14 different leg lengths (chapter 2).
2. **Write the controller once in C++** (`firmware/lib/bolt_core`). The simulator loads that same C++ file, so what is tested is what will be flashed.
3. **Run the tests** (`sim/test_suite.py`): balance, push, speed, slopes, bumps, payload, tilt, crawl, jump, steps, stairs, hop, recovery.
4. **Read failures, fix, repeat.** Most of the work was here: the first jump attempt fell over, the second detected landing in mid‑air, the third spun the body, and so on. Chapter 5 lists every bug and its fix.
5. **Change the design** where the controller can't fix it: V1 → V2 → V3 (chapter 5).

## 1.8 Then the rest of the system

With a body that balances and jumps in simulation, the remaining layers were added and each was tested against the simulated robot:

* the **brain** on the Pi (`companion/`): line following from the camera image, obstacle map from the sonars, shortest‑path planning (A*), Mission Planner link (MAVLink), behaviours (jump, step‑up, dodge…);
* the **phone app** (`app/`): a web page the robot serves, tested in a headless browser;
* the **firmware** around the controller: motor drivers, IMU, sensors, safety (`firmware/src`);
* the **electronics**: power path, buses, pins (`electronics/`, chapter 6).

## 1.9 Be honest about results

Every number in the docs comes from a test that can be re‑run. When a test failed and couldn't be fixed (multi‑step stairs, getting up after a fall), it is written down as a limit with a reason and a fix path. One test was even made *stricter* after it gave a flattering number (push recovery — chapter 5).

## 1.10 Tools used (all free)

| Tool | Used for |
|---|---|
| Python 3, NumPy, SciPy | design maths, LQR (`scipy.linalg.solve_continuous_are`) |
| manifold3d + trimesh | CAD solids, STL export, mass properties |
| MuJoCo | physics simulation and rendering |
| matplotlib | plots and diagrams |
| g++ / arm‑none‑eabi‑g++ | compiling the controller for the PC (sim) and for the Teensy |
| PlatformIO / Teensyduino | building and flashing the Teensy firmware |
| OpenCV | camera image processing |
| pymavlink | talking to Mission Planner |
| aiohttp | the robot's web server for the app |
| Playwright (Chromium) | testing the app automatically |

## 1.11 If you want to reproduce it

```bash
python3 cad/build_parts.py        # parts + masses
python3 sim/lqr_design.py         # controller gains (also writes the firmware header)
python3 sim/test_suite.py V3      # the 15 tests
python3 sim/companion_sim.py --demo all
python3 sim/make_report.py        # the report figures
```
Change something in `design/params.py` and run the same commands to see what your change does.

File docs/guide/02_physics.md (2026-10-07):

# Chapter 2 — The physics behind BOLT

No prior control theory is assumed. Each section starts with the intuition, then gives the equations used in the code, then the actual numbers for BOLT.

## 2.1 Why a two‑wheeled robot falls

Stand a broom on your palm. If it leans a little, gravity pulls its top further over — the lean **grows by itself**. That is an *inverted pendulum*: an unstable system. For a stick of height *h* the lean grows roughly like `e^(t/τ)` with `τ = √(h/g)`. For BOLT's centre of mass (≈ 0.26 m high) `τ ≈ 0.16 s`: left alone, a 1° lean becomes 20° in about half a second. The controller must react many times faster than that — BOLT's loop runs every **1 ms**.

## 2.2 How wheels catch the fall

To keep a broom up you move your hand **under** it. BOLT does the same with its wheels: if the body leans forward, the wheels accelerate forward until they are back under the centre of mass (COM). The wheel motor pushes on the ground through friction; the ground pushes back on the robot.

A surprising consequence: **to drive forward, BOLT must first roll slightly backwards.** It has to lean forward before it can accelerate forward, and the only way to create that lean is to move the wheels back for an instant. Engineers call this *non‑minimum‑phase* behaviour. You can see it in the gains: the position gain has the "wrong" sign (§2.5).

## 2.3 The model the controller is designed on

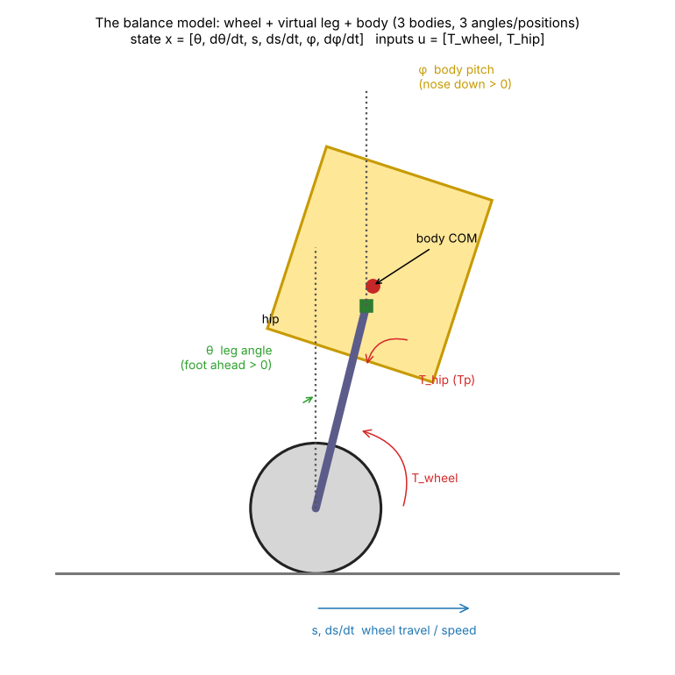
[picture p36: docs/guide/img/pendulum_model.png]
model


The full robot has dozens of moving parts, but for balancing it behaves like three bodies in the side view:

* the **wheel** (both wheels together), rolling without slipping;
* the **virtual leg**: a straight rod from the wheel axle to the hip. Its length is L and its angle from vertical is θ (θ > 0 when the foot is ahead of the hip);
* the **body**, hinged at the hip, tilted by the pitch φ (φ > 0 when the nose goes down).

The robot is described by 3 positions and their 3 speeds: **x = [θ, θ̇, s, ṡ, φ, φ̇]**, where s is how far the wheels have rolled. It has two "levers" (inputs) **u = [T_wheel, T_hip]**: the wheel motor torque, and the hip torque between leg and body.

### Equations (Lagrangian mechanics, as coded in `sim/lqr_design.py`)
Positions in the side view (x forward, z up), with W the wheel centre:

```
W        = (s, R)
leg COM  = W + l_w·(−sin θ, cos θ)                    (l_w = 6.7 cm above the axle)
hip H    = W + L·(−sin θ, cos θ)
body COM = H + (b_x cos φ + b_z sin φ,  −b_x sin φ + b_z cos φ)   (b_x = −5 mm, b_z = +24 mm)
```
* Kinetic energy T = ½ m_w ṡ² + ½ I_w (ṡ/R)² + ½ m_l |v_leg|² + ½ I_l θ̇² + ½ m_b |v_body|² + ½ I_b φ̇²
* Potential energy V = g·(m_l·z_leg + m_b·z_body)
* Generalised forces: the wheel motor turns the wheel relative to the leg, and the hip torque acts between leg and body:

  `Q_θ = T_wheel + T_hip,   Q_s = T_wheel / R,   Q_φ = T_hip`

Lagrange's equation `d/dt(∂T/∂q̇) − ∂T/∂q + ∂V/∂q = Q` gives `M(q)·q̈ + (gravity terms) = Q`. Near the upright pose the speeds are small, so we **linearise**: `q̈ ≈ M⁻¹(K·q + B·u)`. In state‑space form:

```
ẋ = A x + B u        (6×6 matrix A, 6×2 matrix B)
```
The code does this numerically: it builds the energy functions, differentiates them with tiny finite differences, and gets A and B. **All the masses come from the MuJoCo model** (body 4.20 kg, legs 1.19 kg, wheels 1.04 kg, body pitch inertia 0.027 kg·m²…), and those come from the CAD. If the CAD changes, the controller changes with it.

## 2.4 LQR — choosing the gains automatically

The controller is a simple rule: **u = −K·x** (each torque is a weighted sum of the 6 state values). The question is which 12 numbers to put in K. *LQR* (Linear‑Quadratic Regulator) picks the K that minimises

```
J = ∫ ( xᵀ Q x + uᵀ R u ) dt
```
Q says how much you dislike each kind of error, R how much you dislike using torque. BOLT uses
`Q = diag(40, 1, 120, 25, 900, 4)` for [θ, θ̇, s, ṡ, φ, φ̇] and `R = diag(1, 0.35)`. The 900 on φ means "keep the body level above all". The 120 on s means "don't drift away". SciPy solves the Riccati equation (`solve_continuous_are`) and returns K. You never tune 12 gains by hand, only 8 weights with clear meanings.

The result is stable: the slowest closed‑loop pole is at −2.6 s⁻¹, so disturbances decay with a time constant of about 0.4 s.

## 2.5 Reading the gains (L = 0.22 m)

| | θ | θ̇ | s | ṡ | φ | φ̇ |
|---|---|---|---|---|---|---|
| wheel torque | 22.7 | 3.6 | −10.8 | −9.7 | −6.6 | −0.9 |
| hip torque | 5.0 | 0.75 | −2.6 | −2.2 | 50.7 | 3.6 |

* `T_wheel = −22.7·θ…`: if the foot is ahead (θ > 0, robot falling backwards), the wheels drive backwards to get under it.
* The **s gain is negative**: if the robot is ahead of where it should be, the wheels first push it *further forward* to make it lean back, then it rolls back. This is the non‑minimum‑phase effect from §2.2.
* The hip gain on φ is large (50.7 Nm/rad): the hips are what keep the body level, so the legs do the leaning instead.

## 2.6 Gain scheduling

A short pendulum falls faster than a long one, so the best gains depend on L. The design is repeated for 14 leg lengths between 0.12 and 0.36 m. Each gain is fitted with a cubic polynomial in L and stored in `firmware/lib/bolt_core/robot_config_generated.h`. In the firmware, `Controller::gains(L)` evaluates the polynomials every millisecond.

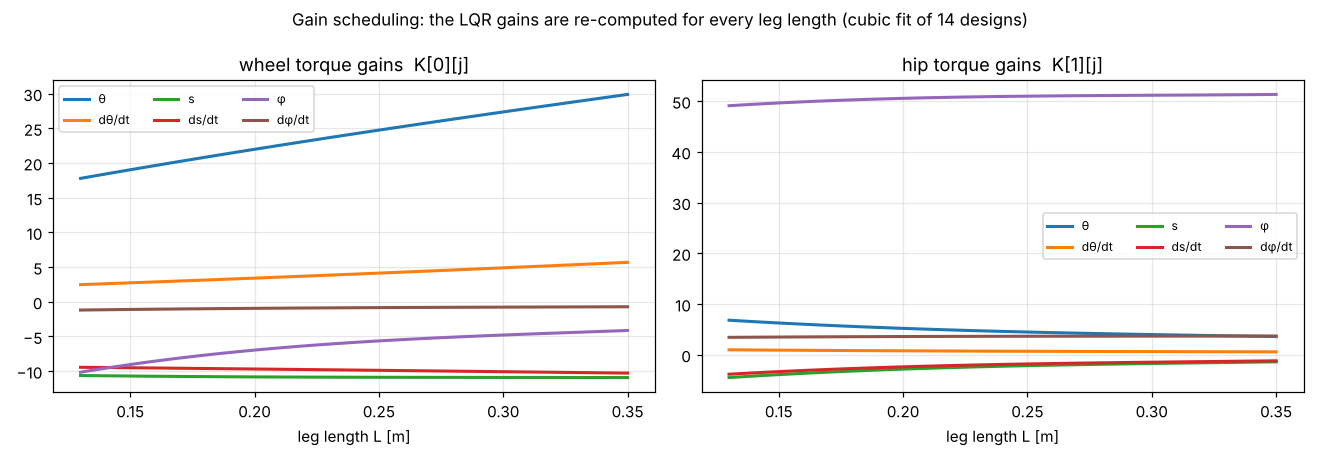
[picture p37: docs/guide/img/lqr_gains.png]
gains


## 2.7 Tilting the body on purpose

To bow forward by φ_ref, the body's COM moves forward of the hip by `x_w = b_x cos φ + b_z sin φ`. To stay balanced, the whole robot's COM must stay above the wheel, so the leg must lean the other way:

```
sin θ_eq = m_b·x_w / ((m_b + ½ m_leg)·L)        T_hip,eq = −m_b·g·x_w
```
The controller adds T_hip,eq as a feed‑forward and regulates around θ_eq (`Controller::equilibrium`). Because BOLT's body COM is only 24 mm from the hip axis, holding a ±23° tilt costs very little torque. That is the main reason the COM was placed there.

## 2.8 The legs as springs (virtual model control)

The leg length isn't part of the LQR model. Each leg is controlled as if it were a **virtual spring‑damper**:

```
F = F_ff + k·(L_ref − L) − c·L̇        F_ff = (m_b·g/2) / cos θ      (gravity feed‑forward)
k = 900 N/m,  c = 45 N·s/m
```
With half the body (2.1 kg) on each leg, the bounce frequency is √(k/m) ≈ 21 rad/s (3.3 Hz) and the damping ratio is c/(2√(k·m)) ≈ 0.5: firm but not harsh. It acts like active suspension over bumps. Chapter 3 shows how F becomes motor torques.

## 2.9 Side slopes and leaning (roll)

On a sideways slope of angle α the uphill wheel is higher. Keeping the body level needs one leg longer by `ΔL ≈ track·tan α` = 0.364·tan 16° ≈ 10 cm (well inside the 22 cm leg range). The roll controller adds `±F_roll` to the two leg forces:

`F_roll = k_r·(roll_ref − roll) − d_r·roll_rate + k_i∫(roll_ref − roll)` with 250 / 18 / 120.

The integral term removes the steady error caused by the slope. Commanding `roll_ref ≠ 0` gives the "lean" feature.

## 2.10 Turning

Turning at speed v with yaw rate ω needs a sideways (centripetal) acceleration `a = v·ω`. At 1.5 m/s and 2 rad/s that is 3 m/s². The body tends to roll outwards. The outer leg pushes extra by `ΔF = m_b·a·h/track` ≈ 4.2·3·0.26/0.36 ≈ 9 N (`F_turn` in the code). Yaw itself is controlled by giving the wheels different torques (`±T_yaw`) with a PI controller on yaw rate. The integral part was added because tyre scrub made the robot turn at only half the commanded rate (chapter 5).

## 2.11 Slopes

On a ramp of angle α, holding still needs a wheel torque of `m·g·sin α·R`. At 25° that is 6.4·9.81·0.42·0.075 ≈ 2.0 Nm total (1 Nm per wheel, peak available 4 Nm). The tyres must not slip: that needs friction μ > tan α = 0.47 (rubber‑like TPU on asphalt is ~0.8). The controller finds this torque by itself: the position error (s − s_ref) grows until `K_s·error` equals it. This acts like an integral term.

## 2.12 Motors have a speed limit (back‑EMF)

A motor turning faster generates a voltage that opposes the battery, so the available torque falls roughly linearly to zero at the no‑load speed:

`τ_available ≈ τ_peak·(1 − ω/ω_max)`

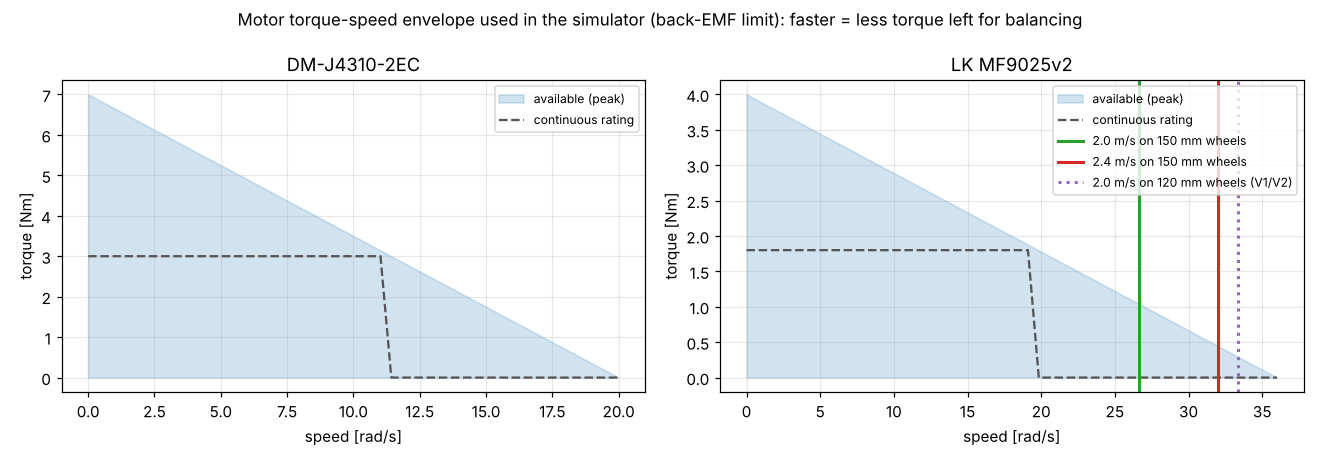
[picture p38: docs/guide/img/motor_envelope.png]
motors


This is why wheel size mattered (chapter 5). At 2 m/s, 120 mm wheels spin at 33 rad/s, which is 93 % of the MF9025's 36 rad/s limit, so almost no torque is left to balance and the robot runs away. 150 mm wheels spin at 27 rad/s (74 %), which leaves enough torque. The simulator applies this envelope to every motor every step.

## 2.13 Jumping — energy bookkeeping

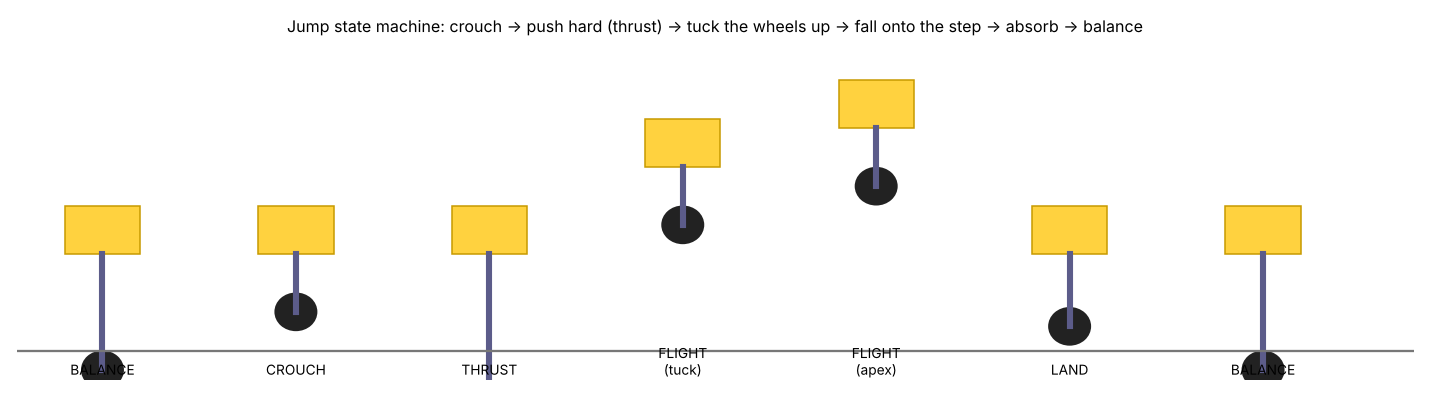
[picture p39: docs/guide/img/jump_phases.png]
jump


To clear a step of height h, the **bottom of the wheel** must rise above h (+5 cm margin). Two things lift the wheel:

1. the robot's COM flies up by `h_com = v_com²/(2g)`;
2. after take‑off the legs retract (from 0.338 to 0.15 m). Pulling the light wheels up toward the heavy body raises the wheels relative to the COM by `ΔL·m_body/m_total`.

So `h_com = h + 0.05 − (0.338 − 0.15)·4.2/6.4`. Example for a 16 cm step:

```
retraction gain = 0.188 × 0.653 = 0.123 m
h_com  = 0.16 + 0.05 − 0.123 = 0.087 m
v_com  = √(2·9.81·0.087) = 1.31 m/s
body speed at take-off = v_com × m_total/m_body = 2.0 m/s
thrust: (2F − m_b g)·(0.4 × stroke) = ½ m_b v²  →  F ≈ 82 N per leg (+10 % margin)
time to apex = v_com/g = 0.13 s
```
The 82 N matches what the simulator logged. The maximum leg force available is 77–165 N depending on L (chapter 3), which is why the wheel clearance tops out around 22 cm.

**Take‑off timing.** The wheel must be above the step before it reaches the edge. During the thrust (~0.15 s) and the climb (~0.1 s) the robot keeps rolling at v, so the controller fires when the remaining distance equals `v·(t_thrust + t_clear) + R + margin`.

**Landing.** In flight nothing pushes on the legs, so any sudden compression means "ground". When it is detected the controller doubles the damping and eases the legs back to normal height over 0.35 s, like bending your knees when you land.

**Body spin.** The leg force passes through the hip, a few millimetres from the body COM. At 300 N even 5 mm makes a 1.6 Nm twist, which spun the body in early tests. The fix is a feed‑forward hip torque that cancels it: `T_ff = −F·(b_z sin θ_b + b_x cos θ_b)`.

## 2.14 Wheel speed and odometry

Rolling without slipping: ground speed = R × (wheel angular speed relative to the ground). The wheel motor measures speed relative to the **shin** it is mounted on, and the shin itself rotates when the leg moves or the body pitches. So:

`ṡ = R·(ω_motor + pitch_rate − α̇_shin)`

where α̇_shin comes from the 5‑bar kinematics. Forgetting this term makes the robot think it moves every time it crouches.

## 2.15 Knowing which way is up (IMU fusion)

The IMU has a gyroscope (accurate but drifts slowly) and an accelerometer (knows where gravity is, but is noisy and confused by accelerations). The **Mahony filter** (`firmware/lib/bolt_drivers/attitude.h`) integrates the gyro and gently pulls the estimate toward the accelerometer's "down". When the accelerometer reads far from 1 g (jumps, impacts) it is ignored. The gyro bias is measured during one second of standing still at power‑up.

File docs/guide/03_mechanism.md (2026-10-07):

# Chapter 3 — The mechanism: how the legs, wheels and body work

## 3.1 The parts of one leg

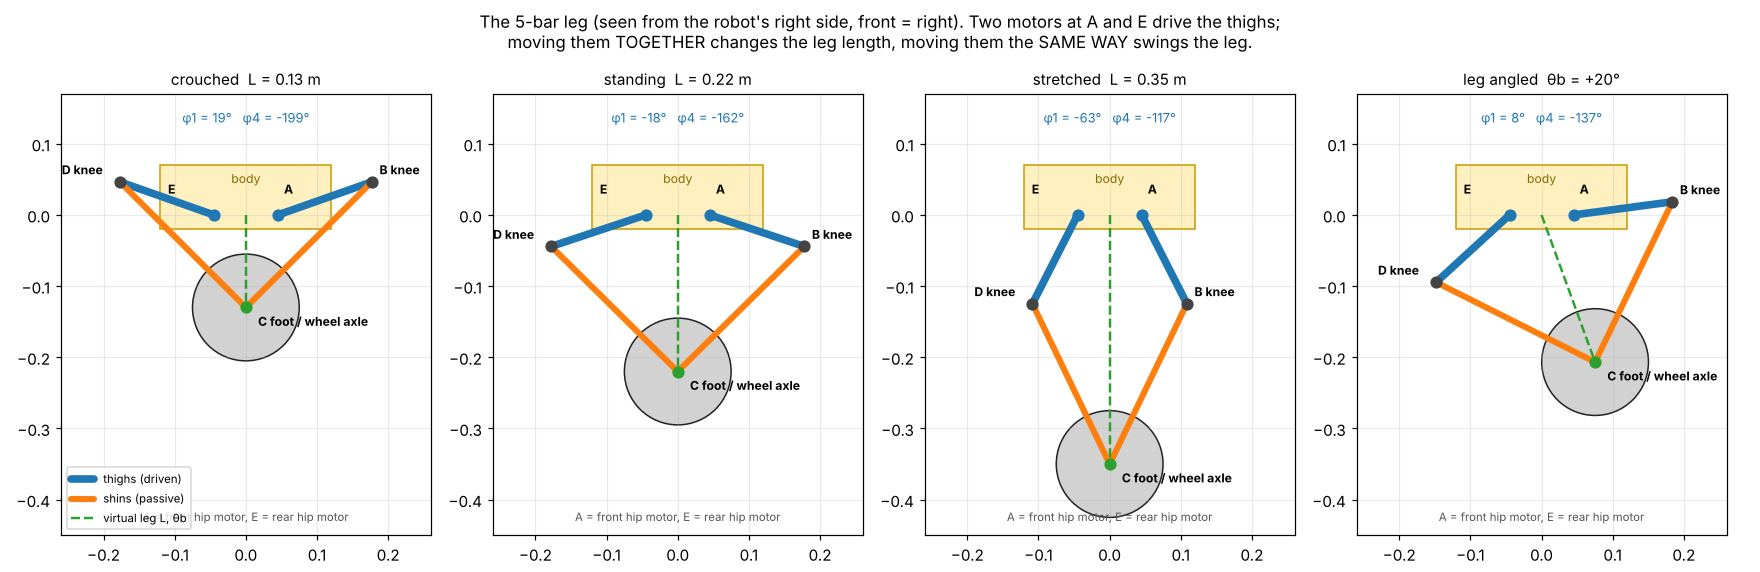
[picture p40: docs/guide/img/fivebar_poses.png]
five-bar


Each side of the robot has one **5‑bar linkage**. Counting the bars:

| Bar | What it is | Length |
|---|---|---|
| 1 (ground link) | the body between the two hip motors A (front) and E (rear) | l5 = 90 mm |
| 2 | **front thigh** A→B, bolted to the front hip motor | l1 = 140 mm |
| 3 | **front shin** B→C | l2 = 250 mm |
| 4 | **rear shin** D→C | l2 = 250 mm |
| 5 | **rear thigh** E→D, bolted to the rear hip motor | l1 = 140 mm |

Joints: A and E are the two **motors**. B and D are **knees** with 608 ball bearings and M8 pins. C is the **foot**, where both shins meet on the wheel axle. The rear shin carries the wheel motor; the front shin rides on a boss of the rear shin with its own bearing.

### Why does it have exactly two degrees of freedom?
Grübler's formula for planar mechanisms: `DOF = 3(n − 1) − 2j`, with n = 5 bars and j = 5 pin joints → `3·4 − 2·5 = 2`. Two motors, two degrees of freedom, so the foot position (x, z) is **fully decided** by the two motor angles. Nothing flops around.

### Why this design instead of a hip + knee motor?
* Both heavy motors (300 g each) sit on the **body**. The leg is only ~240 g of printed links, so it swings and extends very fast, which is what jumping needs.
* Both motors **share** the load: pushing the leg straight down uses both at once (twice the force).
* The geometry acts like a variable gearbox: when crouched the leg is "geared down" (strong, slow), when stretched it is "geared up" (fast).

## 3.2 Forward kinematics: from motor angles to foot position

Angles φ1 (front thigh) and φ4 (rear thigh) are measured from the forward direction, counter‑clockwise in the side view. The code is `design/kinematics.py → forward()` and its C++ twin `firmware/lib/bolt_core/five_bar.h → five_bar_fk()`.

1. Knees: `B = A + l1·(cos φ1, sin φ1)`, `D = E + l1·(cos φ4, sin φ4)`.
2. The foot C is l2 away from **both** B and D, so it is where two circles of radius l2 around B and D intersect. Let `M` = midpoint of BD and `d` = |BD|; then `h = √(l2² − d²/4)`, and C = M + h × (unit vector perpendicular to BD). Of the two intersections, take the one **below** the knees.
3. The **virtual leg**: `L = |C|` (distance from the hip midpoint to the foot) and `θ_b = atan2(C_x, −C_z)`.

**Worked example (standing):** φ1 = −18.4°, φ4 = −161.6°

```
B = (0.045 + 0.140·cos(−18.4°), 0.140·sin(−18.4°)) = (0.178, −0.044)
D = (−0.178, −0.044)            M = (0, −0.044),  d = 0.356
h = √(0.25² − 0.178²) = 0.176   C = (0, −0.044 − 0.176) = (0, −0.220)
→ L = 0.220 m, θ_b = 0       (|BC| = √(0.178² + 0.176²) = 0.250 ✓)
```

## 3.3 Inverse kinematics: from a wanted foot position to motor angles

`inverse()` / `five_bar_ik()`: for a wanted (L, θ_b), compute the foot C. Each thigh–shin pair is then a 2‑link arm reaching C. By the law of cosines, the angle at the motor between the line motor→C and the thigh is `acos((l1² + d² − l2²)/(2·l1·d))`. The front knee bends forward (+) and the rear knee backward (−), so the knees point outward like `/\`. This is used for calibration angles, the CAD poses and setting up the simulation.

## 3.4 The Jacobian: how motor torque becomes leg force

The controller doesn't think in motor torques. It wants "push the leg out with force F" and "rotate the leg with torque T_p". The **Jacobian** J tells how much L and θ_b change when each motor turns a little:

```
J = [ ∂L/∂φ1   ∂L/∂φ4 ]        computed numerically: move one motor by 0.0001 rad,
    [ ∂θ/∂φ1   ∂θ/∂φ4 ]        run the forward kinematics, divide the change by 0.0001
```

**Virtual work** says the work done by the motors equals the work done by the leg: `T1·dφ1 + T4·dφ4 = F·dL + T_p·dθ`. That gives the key formula of the whole leg controller:

```
[T1, T4] = Jᵀ · [F, T_p]
```
**Example (standing):** ∂L/∂φ1 = −0.0888 m/rad, ∂L/∂φ4 = +0.0888 m/rad. Holding half the body (F = 20.6 N, T_p = 0) needs T1 = −1.83 Nm and T4 = +1.83 Nm. That is the motors pulling the two thighs towards each other. The simulator measured −1.80 / +1.89 Nm.

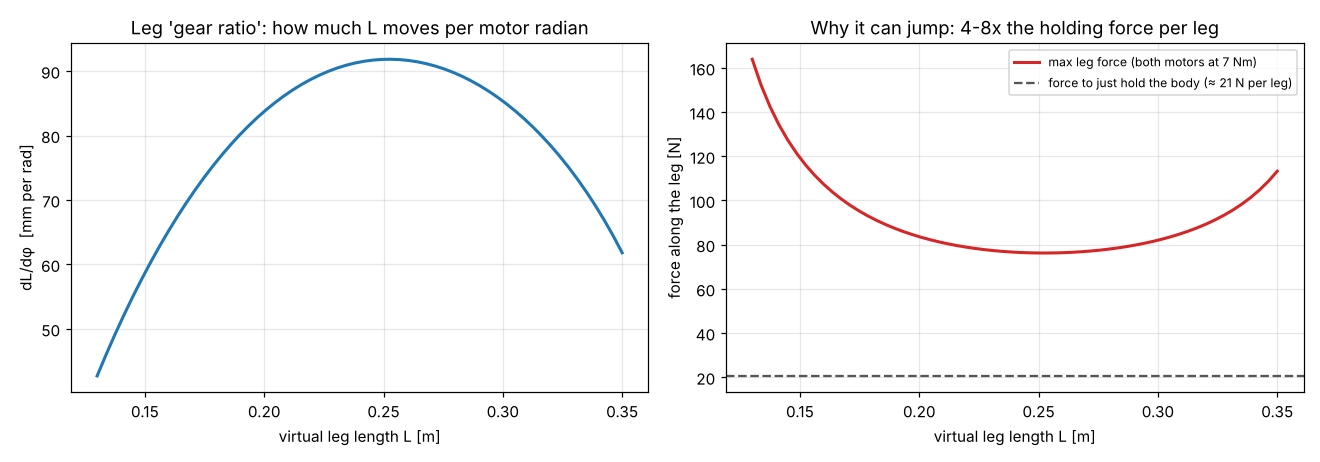
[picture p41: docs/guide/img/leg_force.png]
leg force


The left plot is the "gear ratio" ∂L/∂φ. The right plot is the maximum straight push with both motors at their 7 Nm peak: 165 N when crouched (strong gearing) and 77 N in the middle. Holding still needs only 21 N, so the legs have 4–8× reserve for jumping. If a requested force would need more than 7 Nm on a motor, the code scales the whole command down (`hip_torques()`), so the force direction is kept.

### Singularities and the working range
When the thighs and shins line up (fully stretched, d → 2·l2) or fold onto each other, J loses rank: the leg can't push in some direction and the torques blow up. The working range is limited to L = 0.13–0.35 m, well away from both. At 0.35 m the thighs are still 27° from vertical (`fivebar_poses.png`).

## 3.5 The wheel module

* **Motor**: LK MF9025, an outer‑rotor "pancake" hub motor. The stator bolts to the rear shin (4 × M4). The output face carries the wheel.
* **Rim**: a printed PETG‑CF cup bolted only to the motor's output face (6 × M3), with a 1.5 mm gap to the motor body so it never rubs.
* **Tyre**: printed TPU 95A, 15 mm thick with a chevron tread. It is the robot's main suspension and grip. TPU 85A is softer and grippier.
* **Size**: 150 mm diameter. Bigger rolls over bumps and step lips better and gives more speed for the same motor rpm (chapter 2.12 / 5).

## 3.6 The body (chassis)

**Load path**: wheel → shins → knees → thighs → hip motor output → motor housing → **side plate** → floor plate / top frame → other side. The side plates (8 mm PA‑CF) are the backbone. They carry the four hip motors and are tied into a stiff box by the floor plate (with battery rails) and the top frame (with the electronics sled guides). The yellow shell is only a cover. It holds to the frame with magnets, so a crash pops it off instead of breaking it.

**Where the mass sits (why it balances well):**
* battery (780 g, the heaviest single part) slung **below** the hip axis between the four hip motors;
* payload bay centred **on** the hip axis;
* electronics sled behind it, sensors in the face.

Body COM ends up 5 mm behind and 24 mm above the hip axis. Chapter 2 explains why that helps: tilting and landing cost almost no torque, and acceleration is symmetric.

**Protection:** TPU bumpers ("cheeks") front and rear, TPU skid ribs on the belly pan, the Pi on rubber grommets. The IMU is **hard‑mounted**: a soft mount would add a wobble the controller would try to balance against.

## 3.7 Calibration end stops

The motor encoders know how far they turned, but not where "zero" is relative to the leg geometry. The side plates have two **pegs** that the thighs rest on when the legs are folded fully (L = 0.125 m). That pose has known angles (φ1 = 22.9°, φ4 = −202.9°, computed from the kinematics). `bolt_cli.py calibrate` records the motor positions there and stores the offsets in the Teensy's EEPROM. During normal use the legs never fold that far, so the pegs never touch.

## 3.8 Electronics sled and battery tray

The sled is a vertical plate between the payload bay and the rear of the body: Pi 5 on one face, the Teensy carrier (with the IMU) and the voltage converters on the other. It slides up through the roof in printed guides, clamps with two thumb screws, and connects through one multi‑pin plug plus one XT30 power plug. The battery slides in from the rear on rails in the floor plate and snaps into a latch.

## 3.9 Materials — why each

| Material | Where | Why |
|---|---|---|
| PA‑CF (nylon + carbon fibre) | side plates, frame, thighs, shins | stiff and tough, doesn't crack under impact; anneal for best stiffness |
| PETG‑CF | belly pan, sled, wheel rims | stiff, easier to print than nylon |
| PETG | shell, payload bay, lids | tough, cheap, good surface |
| TPU 95A | tyres, bumpers | rubbery: grip and shock absorption |
| clear/smoke PETG | face visor | the LED eyes glow through it |

Thighs are printed at 100 % infill or 8 walls. During a jump they carry the full motor torque, and walls (perimeters) carry bending load much better than sparse infill.

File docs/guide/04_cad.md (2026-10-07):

# Chapter 4 — How the CAD was made (parts designed by code)

## 4.1 The idea: constructive solid geometry
Instead of clicking in a CAD program, every part is built in Python (`cad/build_parts.py`) from simple solids:

* **add** (`a + b`): glue two solids together;
* **subtract** (`a − b`): drill holes and pockets;
* **intersect** (`a ^ b`): keep only the overlap, for example "the part of the shell below the split line";
* **hull**: shrink‑wrap several shapes (eight spheres → a rounded box; two circles → a link with round ends).

The geometry kernel is **manifold3d**, which guarantees closed, watertight solids that every slicer accepts. **trimesh** exports STL and computes volume and centre of mass.

Why code? Every dimension comes from `design/params.py`, so the parts always match the kinematics and the simulator, and changing the leg length re‑generates everything in about 2 seconds.

## 4.2 Helper functions (top of the file)
| Helper | Makes |
|---|---|
| `box(x0,x1,y0,y1,z0,z1)` | a block from coordinates |
| `cyl(r, h, axis)` | a cylinder along x, y or z (holes, bosses, motors) |
| `rounded_box(…, r)` | hull of 8 spheres: the cute rounded body |
| `rounded_plate_xz` | a flat plate with rounded corners (side plates) |
| `bolt_circle(pcd, n, d…)` | n holes on a circle (motor flanges) |
| `link2d(length, r_a, r_b, w)` | 2‑D outline of a link with round ends, later extruded (thighs, shins) |

## 4.3 How each part is shaped and why
* **Shell (`shell_upper` → front/rear halves).** The outer envelope is a rounded box of 210 × 240 × 230 mm with 42 mm corner radius (the friendly "toaster" look). The shell is the envelope minus the same box shrunk by 3 mm (`envelope(-WALL)`). Then holes are cut: hip slots for the thighs, roof openings for the payload bay and the electronics cartridge, eye windows, the fisheye camera hole and IR LED holes, sonar "mouth" and "cheek" holes angled ±45°, end‑stop peg clearances, vent slots. Magnet bosses are added on the split line. It is cut at x = 0 into two halves so each fits a 256 mm bed.
* **Belly pan.** The lower part of the same envelope with a rear opening for the battery, skid ribs and drain holes.
* **Side plates.** 8 mm structural plates with clearance holes for the motor rotors, motor bolt circles, lightening windows to save weight, edge holes to the floor and top frame, and the **calibration pegs** computed by `end_stop_points()` from the kinematics.
* **Floor plate / top frame.** Tie the side plates into a box. The floor has battery rails and a stop. The top frame has the payload‑bay drop‑in, the sled slot with guide fingers, and heat‑set insert holes for a roof rack.
* **Payload bay / lid.** A 120 × 124 mm box hanging from the top frame, centred on the hip axis, with tie‑down eyelets and drain slots. The lid is cut from the envelope so it follows the roof curve.
* **Electronics sled / cap.** A vertical plate with Pi 5 and Teensy‑carrier standoffs, cable‑tie slots and thumb‑screw holes. The cap carries the short GPS stub and puck seat.
* **Legs.** `link2d` outlines extruded 10 mm. Thigh: motor flange spigot, bolt circle with counter‑bores, knee pin hole, lightening slot. Shins: 608 bearing pocket at the knee. The rear shin has the wheel‑motor stator bolt circle and an axle boss. The front shin has a ring that rides on that boss.
* **Wheel rim + tyre.** The rim is a cup bolted to the motor's output face, with retaining lips. The tyre is a TPU ring with grooves that match the lips and a chevron tread.
* **Bumpers, visor, brackets.** The bumper is a band between envelope+7 mm and the envelope, height‑limited to the "cheeks". The visor is a 1.5 mm skin over the face.

## 4.4 Print orientation
Each part is rotated so its biggest flat face sits on the bed (`print_rot`), then moved so it rests on z = 0 and is centred. Structural plates print flat, so the layers run along the load direction.

## 4.5 Weighing the robot before it exists
For every part the script computes `volume × material density × fill factor` (fill factor ≈ walls + infill, for example PA‑CF 0.70) and the centre of mass. It writes `cad/mass_report.json`. The simulator reads the body total (1.39 kg of prints) and its COM, the per‑leg and per‑wheel print masses. Motors, battery, Pi etc. are added as known catalogue masses at their positions from `params.py`. When you build the real robot, weigh the parts and correct `params.py`. The controller is regenerated from it.

## 4.6 Assembly outputs
* `cad/stl/*.stl` — print‑ready parts;
* `cad/assembly/*.stl` — parts in robot coordinates (metres), used by the simulator as visual meshes;
* `cad/assembly_nominal_pose.stl` — the whole robot standing, legs posed with the inverse kinematics.

## 4.7 Changing the design
* Longer legs: edit `thigh` / `shin` in `design/params.py`, re‑run `cad/build_parts.py`, `sim/lqr_design.py` and the test suite.
* Different motor: edit `HIP_PCD`, `HIP_STATOR_PCD`, `WHEEL_*_PCD` at the top of `cad/build_parts.py` and the motor data in `params.py`.
* Different look: `R_SHELL` (roundness), eye positions in `shell_upper`, colours in `sim/robot_model.py`.

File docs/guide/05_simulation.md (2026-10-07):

# Chapter 5 — How the simulations were done, and how the design was improved

## 5.1 What a physics simulator does
MuJoCo stores the robot as rigid **bodies** connected by **joints**, each with mass and inertia. Every 0.5 ms it:

1. finds which shapes touch (tyre ↔ ground, shin ↔ step edge…);
2. computes contact forces with friction;
3. adds motor torques, gravity and constraint forces;
4. solves Newton's laws for the accelerations and steps positions and speeds forward.

Repeat 2000 times per simulated second and you get the robot's motion. The time step must be much shorter than the fastest thing that happens. Here that is tyre contact and the 1 kHz control loop.

## 5.2 Building the robot model (`sim/robot_model.py`)
The script writes an MJCF (MuJoCo XML) file from `design/params.py`:

* **base body** with a free joint (it can fly, which is needed for jumps). Its mass is built from boxes for every component: shell prints at their CAD centre of mass, battery, sled, sensors, four hip motors. One box approximates the body's collisions.
* **per side:** `thigh_F` (hinge at A) → `shin_F` (hinge at B); `thigh_R` (hinge at E) → `shin_R` (hinge at D) → `wheel` (hinge at C).
* **closing the loop:** a tree can't contain a loop, so the front shin's tip is tied to the rear shin's tip with an **equality constraint** (`<connect>`). That turns the two open chains into the real 5‑bar. The legs are placed in the exact closed pose from the inverse kinematics at start, so the constraint starts satisfied. This was checked: foot positions agree to 1e‑17 m.
* **contacts:** cylinders for the tyres (friction 1.0), capsules for the shins (so a knee can hit a step), the GPS puck (crawl height). Robot parts collide with the world but not with each other.
* **actuators:** torque motors on the 4 hip joints and 2 wheel joints.
* **sensors:** gyro and accelerometer at the IMU position; ultrasonics are 3 rays per sensor spread over its cone; IR cliff sensors are rays 30° forward of down; two cameras where the fisheyes are.
* **visuals:** the CAD meshes, so renders look like the real robot.
* **terrains:** flat, ramp, side slope, random height‑field (rough), steps/stairs, bars, gaps, obstacles, a textured floor with a coloured line.

## 5.3 Making the simulation honest
A simulation that is too perfect gives false confidence. These real‑world effects are added (`sim/simulator.py`):

| Effect | Implementation |
|---|---|
| motor speed limits | torque clipped to the back‑EMF envelope (chapter 2.12) for every motor |
| bus latency | the torque computed this millisecond is applied next millisecond |
| sensor noise | IMU angles ±0.002 rad, gyro ±0.004 rad/s, encoders, wheel speed |
| sonar behaviour | minimum of 3 rays, 4 m max, 1 cm noise |
| GPS | random slow wander of the position (±0.3 m) |
| camera | images rendered from the robot's camera and processed by the real OpenCV code |

## 5.4 One controller for both worlds
The controller (`firmware/lib/bolt_core/bolt_controller.cpp`) is written in plain C++ with no Arduino calls. `sim/controller.py` compiles it into `libbolt.so` and calls it through **ctypes**, using Python structures that mirror the C++ structs byte for byte (sizes are checked at load time). The loop each millisecond:

```
read simulated IMU + joint encoders  ->  Inputs struct
bolt_step(controller, Inputs, Command, Outputs)     # the firmware code
apply motor torque limits  ->  MuJoCo actuators  ->  2 physics steps
```
On the Teensy, `main.cpp` does exactly the same with real sensors and CAN motors.

## 5.5 Designing the controller from the model
`sim/lqr_design.py` (details in chapter 2):

1. builds the MuJoCo model and poses the legs at 14 lengths;
2. measures the lumped masses, COM offsets and inertias of body, legs and wheels from MuJoCo;
3. builds the 3‑body wheel–leg–body equations and linearises them numerically;
4. solves LQR at each length and fits cubic polynomials;
5. writes `sim/build/config_<variant>.json` (for the sim) and `firmware/lib/bolt_core/robot_config_generated.h` (for the Teensy).

So a change in the CAD flows automatically into the gains.

## 5.6 The test suite (`sim/test_suite.py`)
Each requirement became a function that sets up a scene, drives the robot with a scripted "operator", and measures pass/fail:

| Test | Scene and pass criterion |
|---|---|
| static_balance | stand 5 s with sensor noise; report pitch RMS and drift |
| push_recovery | shove the body for 0.1 s; binary search for the biggest impulse it recovers from **cleanly** (no fall, legs never past ±45°, calm stance after 4 s) |
| top_speed | 1.0 / 2.0 / 2.4 m/s; must track (< 120 % of command) with < 10° pitch |
| turning | 1.5 m/s with 2 rad/s yaw; report body roll |
| incline | 10–30° ramps: climb to the plateau **and** stop half way and hold for 3 s |
| side_slope | 8–16° sideways slope; body must stay within 4° of level |
| rough_terrain | random bumps 5–14 cm at 0.8 and 1.5 m/s; must cross 4 m |
| payload | 0–3 kg in the bay; drive and survive an 8 N·s push |
| tilt_height | pitch ±0.2/0.4 rad, roll ±0.25 rad, min/max height; measure what is achieved |
| crawl | crawl mode under bars at 0.38–0.50 m |
| jump_flat | requested heights 0.1/0.2/0.3 m; measure wheel clearance |
| step_up | steps 8–22 cm, run‑up at 1 m/s, jump requested at 0.7/0.9/1.1 m; success rate |
| stairs | 3 steps, treads 0.30/0.45/0.60 m, using the stair policy |
| obstacle_hop | hop over 6/10/14 cm bars |
| fall_recovery | tip it over with motors off, then try to self‑right |

The 45 test runs (15 tests × 3 designs) run in parallel on 4 cores in under a minute. Results go to `sim/results/<variant>.json`.

## 5.7 Iterating the design: V1 → V2 → V3

iterations
COM

**V1 "big head".** The first sketch went for the cartoon look: battery and sensors up in the head, 120 mm wheels, narrow 300 mm track. Body COM 74 mm above the hip. Result: it balanced, but recovered cleanly only from 8.2 N·s pushes, and at 2 m/s it **ran away and fell**. The motors ran out of speed (chapter 2.12).

**V2 "low COM".** The battery moved under the hip axis and the track widened to 364 mm. Body COM fell to +29 mm, push recovery rose to 9.1 N·s, and it crawled under a lower bar (0.40 m). It still ran away at 2 m/s, because the wheels were the same.

**V3 final.** 150 mm wheels (2 m/s now uses 74 % of the motor speed instead of 93 %), longer shins for more jump stroke, the payload bay sunk onto the hip axis, and the real CAD masses. **Safe top speed doubled to 2.0 m/s**, push recovery reached 10 N·s, jump clearance 22 cm. Trade‑off: the bigger wheel gives less pushing force per Nm, so the steepest ramp dropped from 30° to 25° (still above the 20° target), and the robot gained 0.7 kg.

The lesson: change **one idea per iteration** and keep the tests identical, so you know what each change bought.

## 5.8 Iterating the controller: the bug diary
Most of the work was here. The tests found each problem; detailed logs found the cause.

| # | What the test showed | Cause found in the logs | Fix |
|---|---|---|---|
| 1 | first jump falls over | crouch too abrupt (leg swung 15°), thrust stopped early, landing never detected | ramp the crouch, wait until legs are vertical, plan thrust from energy |
| 2 | "landed" while still 20 cm in the air | the accelerometer feels the legs' internal pull, not just the ground | detect touchdown by **leg compression** after apex |
| 3 | body spins nose‑down after take‑off | leg force 5 mm off the body COM, and the wheel spinning up as it unloads | feed‑forward hip torque cancelling the moment; wheel torque limited in thrust; legs held in the body frame in flight |
| 4 | wheel clips the step lip | legs extended for landing too early | two jump modes: "onto a step" stays tucked |
| 5 | step jumps only work in a 5 cm window | crouch takes a variable time | give the controller the edge distance; it fires when `remaining ≤ v·(t_thrust + t_clear) + R + margin` |
| 6 | knee hits the step edge | the front knee sticks out in front of the wheel | include it in the take‑off distance |
| 7 | after landing the robot reverses at 2× the commanded speed | stored position error makes it "catch up" | re‑anchor the position reference when starting or reversing, keep it when stopping (so it still holds on slopes) |
| 8 | that fix broke ramp climbing | anchoring on every change removed the slope‑holding integral | anchor only on start / reverse |
| 9 | turns at half the commanded rate | tyre scrub vs a P‑only yaw loop | yaw‑rate PI |
| 10 | push test said 21 N·s | the robot "survived" with legs flailing through 120° | stricter test → honest 10 N·s |
| 11 | camera rendered garbage | several OpenGL contexts in one process | close each renderer after use |

## 5.9 Software‑in‑the‑loop: testing the brain
`sim/companion_sim.py` connects the real Raspberry Pi code to the simulated robot through `SimRobotIO`. That class returns telemetry, rendered camera frames, sonar/cliff readings and a virtual GPS, and accepts the same `Command` messages the Teensy would.

* **Line following.** A floor texture with a red track with S‑bends. The camera image goes through the real `LineFollower`. Gains were tuned by a parallel sweep. Result: 2.6 cm mean error, by day and in a dark scene where the brain switches the headlight on.
* **Obstacles.** A wall with a gap: the occupancy grid + A* finds the detour. A closed box: it scans 360° and halts with "no alternative path".
* **Mission Planner.** A pymavlink "ground station" uploads a 4‑item mission over real UDP, arms and starts it. The robot follows the shortest street routes on a street grid. A broken‑down van blocks the shortest street, and the robot detours around the block.
* **App.** A headless Chromium opens the real app, drives, jumps, crawls, adds a waypoint and presses E‑STOP.

## 5.10 What the simulation can't promise
Real tyres, gearbox backlash, flexing prints, cable drag, real lighting and fisheye distortion are only approximated. Treat the numbers as "the design is capable of this", then re‑tune on the real robot (chapter 7 has the recipes).

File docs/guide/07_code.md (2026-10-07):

# Chapter 7 — How the code works

The software has four layers. Each one only talks to the layer next to it:

```
app/ (phone)  ⇄  companion/ (Raspberry Pi, Python, 20 Hz)  ⇄  firmware/ (Teensy, C++, 1000 Hz)  ⇄  motors & sensors
                                   ↑ sim/ replaces the hardware below the Pi, or below the controller
```

## 7.1 Firmware: `firmware/src/main.cpp`

**`setup()`** runs once at power‑up:
1. starts USB serial and the pins (e‑stop sense, lights, buzzer);
2. starts the three CAN buses at 1 Mbit/s, each with a receive callback (`on_can_hip`, `on_can_wheel`) that decodes motor replies in the background;
3. starts the IMU. If it isn't found, the motors are never enabled (eyes turn angry, buzzer beeps);
4. averages 1000 gyro samples (1 s, robot still) for the **gyro bias** and sets the starting attitude from gravity;
5. loads the leg calibration from EEPROM, creates the controller with the generated gains (`bolt::default_config()`);
6. enables the motors, starts the **watchdog** (100 ms) and a hardware timer that sets `tick = true` every millisecond.

**`loop()`** runs as fast as possible. It handles CAN events, incoming Pi frames and sonars, and when `tick` is set, one **control cycle**:

```
1. read IMU (14 bytes over SPI), subtract bias, rotate into body axes
2. Mahony filter -> roll, pitch, yaw; unwrap yaw; vertical acceleration
3. legs: motor positions -> φ1, φ4 per leg (sign + calibration offset), speeds; wheel speeds
4. battery filter, e-stop, command timeout (no command for 0.3 s -> v = 0)
5. ctrl->step(in, cmd, out)            <- the shared controller (7.2)
6. send 4 hip torques (DM "MIT" frames) and 2 wheel torques (LK 0xA1 frames)
7. every 10th cycle: cliff sensors + telemetry to the Pi;  every 33rd: eyes
```

### Motor drivers: `firmware/lib/bolt_drivers/motors.h`
**DM‑J4310 "MIT" frame.** Five numbers are squeezed into 8 bytes: position p (16 bits), velocity v (12), stiffness kp (12), damping kd (12), feed‑forward torque t (12). Each real number is mapped linearly onto the integer range: `u = (x − min)/(max − min)·(2^bits − 1)`. BOLT sends pure torque (p = v = kp = 0, kd = 0.02). Example, T = −1.83 Nm with TMAX = 10:

```
p = 0x8000, v = 0x800, kp = 0x000, kd = 0x010, t = (−1.83+10)/20·4095 = 0x689
bytes: 80 00 80 00 00 01 06 89
```
The reply holds the motor's position, speed, torque and temperatures, unpacked by `dm_parse`.

**LK MF9025.** Command byte `0xA1` = torque control. Torque → current (`/ WHEEL_KT`) → a 16‑bit value where ±2048 means ±16.5 A. The reply has temperature, current, speed (degrees per second) and a 16‑bit encoder, which `lk_parse` unwraps into a continuous angle.

### Other drivers
* `icm42688.h`: register setup (2000 °/s, 16 g, 1 kHz, anti‑alias filters) and a 14‑byte burst read.
* `attitude.h`: the Mahony filter (chapter 2.15).
* `sensors.h`: interrupt‑driven sonar timing, the Sharp voltage‑to‑distance curve.
* `eyes.h`: draws expressions (happy = upper half of the rings, sleepy = lower half, blinking…) on the 24 LEDs.

## 7.2 The controller: `firmware/lib/bolt_core/bolt_controller.cpp`

`Controller::step(Inputs, Command, Outputs)` is the heart of BOLT. In order:

1. **Leg kinematics** (`five_bar_solve`): L, θ_b, Jacobian for each leg. Leg speeds L̇ and θ̇ = J·φ̇. World leg angle θ = θ_b − pitch. Wheel ground speed with the shin‑rotation correction (chapter 2.14). Odometry s.
2. **Mode logic**: OFF → BALANCE (if upright) or RECOVER; any state → FALLEN if tipped.
3. **References**: speed ramped by the acceleration limit, height slewed at 0.35 m/s (and lowered at high speed), pitch/roll targets clamped. A new `jump_seq` from the Pi starts the **jump planner** (chapter 2.13), which computes take‑off speed, thrust force and apex time, then switches to CROUCH.
4. **Balance law**: gains for the current L, equilibrium for the commanded pitch, state error x, then `T_wheel = −K₀·x` and `T_hip = T_eq − K₁·x`. The position reference is re‑anchored only when starting or reversing.
5. **Yaw**: PI on yaw rate → ±T_yaw on the wheels.
6. **Legs**: target lengths (roll lean), roll PD+I, turn compensation, gravity feed‑forward.
7. **State machine** `switch (st_)`: CROUCH / THRUST / FLIGHT / LAND adjust targets, gains and limits (chapter 2.13).
8. **Contact estimate** per leg (normal force from leg force + wheel inertia), airborne detection.
9. **Leg torque split**: average leg torque ± a sync term that keeps both legs at the same angle; in flight, hold the legs in the body frame; during thrust and flight add the anti‑spin feed‑forward.
10. **Output**: `[T1, T4] = Jᵀ·[F, T_p]` with torque limits, wheel torques with limits, plus telemetry fields.

The file has no Arduino code, which is why it compiles both for the PC (simulation) and the Teensy. The bottom of the file exports a small C API (`bolt_create`, `bolt_step`…) for Python ctypes.

`five_bar.h` holds the kinematics. `robot_config_generated.h` is written by `sim/lqr_design.py`; never edit it by hand.

## 7.3 The Pi ↔ Teensy protocol: `firmware/lib/bolt_link/bolt_link.h` and `companion/robot_brain/link.py`
Every message is a frame:

```
A5 5A | type | length | payload ... | CRC16 (2 bytes, little-endian)
```
The two sync bytes mark the start. The CRC (a checksum) detects corrupted bytes, which are then ignored. The decoder is a small state machine fed one byte at a time, so it re‑synchronises after garbage. A real command frame (mode = balance, v = 1.0 m/s, yaw = 0.5 rad/s, height 0.22 m):

```
A5 5A 01 16 | 01 00 00 00 E8 03 F4 01 DC 00 00 00 00 00 00 00 00 00 00 00 00 00 | BB 81
            mode flags seq   v=1000 yaw=500 h=220 ...                               CRC
```
Units are integers (mm/s, mrad, mm) to keep frames small. The C++ struct and the Python `struct` format string must stay identical. `companion/tests/test_link.py` compiles a C++ helper and checks byte‑for‑byte compatibility in both directions.

## 7.4 The brain: `companion/robot_brain/`

| File | What it does |
|---|---|
| `main.py` | starts everything: brain thread (20 Hz), app web server, MAVLink endpoint, copies the robot state to Mission Planner |
| `io_real.py` | real hardware: Teensy link, two Picamera2 cameras, GPS reader |
| `behaviors.py` | **the Brain**: modes, actions, reflexes, pose estimate |
| `perception/line_follower.py` | coloured line → steering |
| `perception/obstacles.py` | sonar filtering, obstacle points, drop‑off detection |
| `perception/step_detector.py` | camera → distance to a step edge (experimental) |
| `navigation/planner.py` | occupancy grid, A* on the grid, road graph A*, pure pursuit, local navigator with halt |
| `mission/mavlink_vehicle.py` | pretends to be an ArduPilot rover for Mission Planner |
| `gps.py` | NMEA parsing, lat/lon ↔ metres |
| `app_server.py` | serves the app, WebSocket commands, MJPEG video |
| `link.py` | the protocol from 7.3 |

### `Brain.step()` — one tick (every 50 ms)
```
telemetry + GPS fix            -> update pose (odometry + IMU yaw, slowly corrected by GPS)
sonars + cliff sensors         -> filtered ranges, obstacle points into the occupancy grid
if an action is running        -> take (v, w) from the action generator
else by mode: MANUAL (joystick) | LINE | EXPLORE | MISSION / GUIDED / RTL
reflexes                       -> drop-off ahead: back up; < 0.3 m to an obstacle: no forward speed
lights                         -> dark camera image: headlight + IR on
send Command to the Teensy
```
**Actions are Python generators.** `_act_dodge` is a function that `yield`s (speed, turn) once per tick: turn 50°, burst forward, turn back. The brain calls `next()` every tick. This makes multi‑step behaviours easy to write and read, with no threads or state machines.

### Line following (`line_follower.py`)
1. Keep the lower 45 % of the image (the floor just ahead), blur, convert to HSV (hue/saturation/value), so a colour is a range of hue.
2. Mask pixels in the colour's HSV range, remove specks.
3. Find the line's centre in a near band and a far band → **offset** (where the line is) and **angle** (where it's going).
4. Yaw rate = −(6.0·error + 0.3·d(error)/dt), with error = offset + 0.4·angle. Speed drops in curves.
5. Line lost for 4 s, or blocked for 5 s → HALT and alert.

### Obstacle avoidance and halting (`planner.py`)
* **Occupancy grid**: the world around the robot as 10 cm cells, each holding a "log‑odds" number. A sonar hit adds evidence of an obstacle; the cells along the beam lose evidence (they're free). It scrolls with the robot.
* **Inflation**: cells within 28 cm of an obstacle count as blocked, so the robot's centre never gets close enough to hit.
* **A\***: the classic shortest‑path search. It expands cells in order of `cost so far + straight‑line distance to goal`, so it finds the shortest path while exploring as little as possible.
* **Pure pursuit**: drive towards a point ~0.8 m ahead on the path; turn rate ∝ heading error.
* **`LocalNavigator`**: replans every 0.5 s. If A* finds nothing, turn on the spot (sonars only see forward) and keep trying. If a full 360° turn finds nothing → **HALT, "no alternative path"**. On missions the brain first marks that road blocked and asks the road graph for another route.

### GPS missions (`planner.RoadGraph` + `mavlink_vehicle.py`)
* Roads are loaded from GeoJSON (export OpenStreetMap streets for your area). Points closer than 0.5 m are merged into graph nodes; edges carry their length.
* `shortest_path` runs A* with the great‑circle (haversine) distance as the heuristic.
* MAVLink handshake with Mission Planner:
  1. heartbeat ("I'm a rover");
  2. GCS sends `MISSION_COUNT`; the robot requests each item (`MISSION_REQUEST_INT`) and stores it, then sends `MISSION_ACK`;
  3. `ARM` + `MISSION_START`: the brain switches to MISSION;
  4. the robot sends position, attitude, GPS, battery and status texts several times per second.

### App server (`app_server.py`) and app (`app/`)
The Pi serves `app/` as a website. The page opens a **WebSocket** (a two‑way connection) and sends small JSON messages such as `{"type":"drive","v":0.8,"w":-0.3}` ten times a second while you touch the joystick. Ten times a second the server sends back the whole brain state (`Brain.snapshot()`) to update the screen. Video is MJPEG: an endless HTTP response of JPEG images the `<img>` tag displays. `manifest.webmanifest` + `sw.js` (service worker) make it installable and usable offline on the robot's own Wi‑Fi.

## 7.5 The simulation code: `sim/`
| File | Role |
|---|---|
| `robot_model.py` | builds the MuJoCo XML from params + CAD |
| `lqr_design.py` | controller design → gains → firmware header |
| `controller.py` | compiles and wraps the C++ controller (ctypes) |
| `simulator.py` | `BoltSim`: sensors with noise, latency, motor limits, logging, rendering |
| `test_suite.py` | the 15 tests, parallel runner, results JSON |
| `companion_sim.py` | `SimRobotIO`: the real brain driving the simulated robot; demos |
| `make_report.py` | report figures and GIFs |

## 7.6 Tests you can run
```bash
python3 -m pytest -q companion/tests     # protocol byte-compatibility, GPS, A*, re-routing, grid
python3 sim/test_suite.py V3             # physics requirements
firmware/tools/check_build.sh            # firmware compiles + links for the Teensy (needs arm-gcc + Teensy core)
```

## 7.7 Recipes: how to change things
| I want to… | Change | Then run |
|---|---|---|
| make the body stiffer / softer in pitch | `Q_DIAG` (5th weight) in `sim/lqr_design.py` | `lqr_design.py`, test suite, reflash |
| softer suspension | `kp_leg`, `kd_leg` in `lqr_design.py` | same |
| allow faster driving | `v_max` in `lqr_design.py` (check the motor envelope!) | same |
| support a different line colour | add an HSV range to `COLORS` in `line_follower.py` | — |
| add a new app button | button in `app/index.html`, handler in `app/app.js` sending `{"type":"action","name":"x"}`, a generator `_act_x` in `behaviors.py` registered in `start_action` | test with `sim/companion_sim.py --demo app` |
| add a mission command | a new `cmd` branch in `Brain._mission()` | — |
| change pins | `firmware/src/config.h` + `electronics/make_diagrams.py` | rebuild firmware, regenerate diagrams |
| change motor direction | the `sign` fields in `config.h` | check with `bolt_cli.py status` |
| re‑tune on the real robot | change gains in the sim first, run the suite, then flash | — |

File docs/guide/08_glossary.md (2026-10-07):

# Chapter 8 — Glossary and learning path

## Glossary
| Term | Meaning |
|---|---|
| **A\*** | shortest‑path search that uses an estimate of the remaining distance to search efficiently |
| **actuator** | something that makes motion (here: motors) |
| **back‑EMF** | the voltage a spinning motor generates against its supply; limits torque at high speed |
| **buck converter** | efficient circuit that steps a voltage down (22 V → 5 V) |
| **CAN bus** | robust 2‑wire differential bus used for the motors |
| **COM** | centre of mass, the point where the robot's weight effectively acts |
| **controller (LQR)** | the rule that computes torques from the measured state; LQR = linear‑quadratic regulator, finds the optimal gains |
| **CRC** | checksum that detects corrupted messages |
| **ctypes** | Python module used to call C/C++ code; how the sim runs the firmware controller |
| **DOF** | degrees of freedom, the number of independent ways something can move |
| **equality constraint** | in MuJoCo, a rule that keeps two points together; closes the 5‑bar loop |
| **feed‑forward** | adding the torque you *know* you'll need, instead of waiting for an error |
| **five‑bar linkage** | 5 links in a loop with 2 motors; BOLT's leg |
| **gain scheduling** | switching or interpolating controller gains as conditions (here leg length) change |
| **GeoJSON** | text format for map shapes (roads as lines of lat/lon points) |
| **IMU** | inertial measurement unit: gyroscope + accelerometer |
| **inverse kinematics** | finding joint angles that put the foot where you want it |
| **Jacobian** | table of how much each output (L, θ) changes per joint movement; maps forces to torques by its transpose |
| **Lagrangian mechanics** | deriving equations of motion from kinetic and potential energy |
| **linearisation** | approximating the equations near a pose as straight‑line (linear) relations |
| **log‑odds grid** | map whose cells accumulate evidence of being occupied or free |
| **Mahony filter** | fuses gyro and accelerometer into an attitude estimate |
| **MAVLink** | messaging protocol used by drones/rovers and Mission Planner |
| **MJCF** | MuJoCo's XML model format |
| **MuJoCo** | the physics simulator used here |
| **NMEA** | text format GPS receivers speak |
| **non‑minimum phase** | a system that first moves the "wrong" way (roll back before going forward) |
| **odometry** | estimating travel from wheel rotation |
| **PWM** | switching a signal on and off fast; the on‑fraction sets average power |
| **pure pursuit** | path follower that steers towards a point a fixed distance ahead on the path |
| **PWA** | progressive web app: a web page installable like a phone app |
| **Riccati equation** | the equation whose solution gives the LQR gains |
| **SIL** | software‑in‑the‑loop: real software driving a simulated robot |
| **singularity** | linkage pose where it loses the ability to move/push in some direction |
| **SPI / I²C / UART** | common chip‑to‑chip communication buses |
| **state (x)** | the minimal set of numbers that describes the robot's motion now |
| **TVS diode** | clamps voltage spikes |
| **virtual leg** | the imaginary straight line from hip to wheel that the controller reasons about |
| **virtual work** | power in = power out → relation between joint torques and leg forces |
| **watchdog** | timer that resets the processor if the program stops responding |

## A learning path for a beginner
1. **Programming**: Python basics, then C/C++ basics (Arduino is a good start).
2. **Electronics**: Ohm's law, voltage dividers, using a multimeter, a few Arduino sensor projects (ultrasonic, IMU, LEDs, a MOSFET).
3. **Mechanics**: free‑body diagrams, torque = force × distance, levers. Then planar linkages: draw this repo's 5‑bar on paper and compute one pose by hand (chapter 3.2).
4. **Dynamics and control**: build a simple two‑wheeled balancing robot with a PID controller first. Then learn state‑space and LQR (Brian Douglas' "Control Systems" videos are excellent), and re‑derive chapter 2.3.
5. **Simulation**: MuJoCo's tutorial notebooks; then read `sim/robot_model.py` and change one parameter in `design/params.py` to see what happens in `sim/test_suite.py`.
6. **Robotics software**: OpenCV basics (colour thresholding), A* on a grid (many visual tutorials), then ArduPilot/MAVLink concepts.
7. **Build in stages**: one leg on a bench, then both legs with the robot held, then balancing with a safety tether, then jumps on soft ground.

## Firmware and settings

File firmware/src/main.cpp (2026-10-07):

// BOLT - wheel-legged balancing robot, real-time firmware for Teensy 4.1.
//
//   1 kHz : IMU -> attitude -> whole-body controller (lib/bolt_core) -> 6 CAN motors
//   100 Hz: telemetry to the Raspberry Pi (USB serial, lib/bolt_link)
//   ~30 Hz: eyes / lights, sensors
//
// Safety layers (independent):
//   * hardware e-stop cuts motor power (and is sensed on PIN_ESTOP_SENSE)
//   * motors' own CAN timeout (50 ms, set in the DM tool) -> they go limp if this code hangs
//   * Teensy watchdog (WDOG1) resets the MCU if the loop stalls > 100 ms
//   * command timeout from the Pi -> stop and keep balancing in place
//   * tilt / fall detection in the controller -> limp, protects the electronics
//   * battery under-voltage -> slow down, then sit down and switch the motors off
#include <Arduino.h>
#include <EEPROM.h>
#include <FlexCAN_T4.h>
#include <Watchdog_t4.h>

#include "attitude.h"
#include "bolt_controller.h"
#include "bolt_link.h"
#include "config.h"
#include "eyes.h"
#include "icm42688.h"
#include "motors.h"
#include "robot_config_generated.h"
#include "sensors.h"

FlexCAN_T4<CAN1, RX_SIZE_256, TX_SIZE_16> can1;
FlexCAN_T4<CAN2, RX_SIZE_256, TX_SIZE_16> can2;
FlexCAN_T4<CAN3, RX_SIZE_256, TX_SIZE_16> can3;
WDT_T4<WDT1> wdt;

ICM42688 imu(PIN_IMU_CS);
att::Mahony ahrs;
Sonars sonars;
DMAMEM byte eyes_buf[Eyes::N * 12];
Eyes eyes(PIN_EYES, eyes_buf);

bolt::Controller* ctrl = nullptr;
bolt::Inputs in{};
bolt::Command cmd{};
bolt::Outputs out{};

motors::DmState hip[4];
motors::LkState wheel[2];
float hip_offset[4] = {0, 0, 0, 0};   // motor position at the calibration pose
bool calibrated = false;

link::Decoder rx;
uint32_t last_cmd_ms = 0;
float yaw_unwrapped = 0, yaw_prev = 0;
float gyro_bias[3] = {0, 0, 0};
volatile bool tick = false;
IntervalTimer timer;
uint8_t eyes_expr = Eyes::NORMAL, eye_r = 60, eye_g = 230, eye_b = 255;

// ------------------------------------------------------------------ EEPROM calibration
struct CalBlob { uint32_t magic; float off[4]; };
constexpr uint32_t CAL_MAGIC = 0xB017CA1Bu;

void load_calibration() {
  CalBlob c;
  EEPROM.get(0, c);
  if (c.magic == CAL_MAGIC) {
    memcpy(hip_offset, c.off, sizeof(hip_offset));
    calibrated = true;
  }
}

void store_calibration() {
  // legs are resting on the printed end stops: phi = CAL_PHI
  CalBlob c{CAL_MAGIC, {}};
  for (int i = 0; i < 4; ++i) {
    const float cal_phi = (i % 2 == 0) ? CAL_PHI1 : CAL_PHI4;
    c.off[i] = hip[i].pos - HIP[i].sign * cal_phi;     // phi = sign * (pos - off)  -> off = pos - sign*phi
    hip_offset[i] = c.off[i];
  }
  EEPROM.put(0, c);
  calibrated = true;
}

inline float hip_phi(int i) { return HIP[i].sign * (hip[i].pos - hip_offset[i]); }
inline float hip_dphi(int i) { return HIP[i].sign * hip[i].vel; }

// ------------------------------------------------------------------ CAN helpers
template <typename BUS>
void send(BUS& bus, uint16_t id, const uint8_t d[8]) {
  CAN_message_t m;
  m.id = id;
  m.len = 8;
  memcpy(m.buf, d, 8);
  bus.write(m);
}

void can_send_hip(int i, const uint8_t d[8]) {
  if (HIP[i].bus == 1) send(can1, HIP[i].id, d);
  else send(can2, HIP[i].id, d);
}

void on_can_hip(const CAN_message_t& m) {
  for (int i = 0; i < 4; ++i)
    if (m.id == HIP[i].master) {
      motors::dm_parse(m.buf, DM_PMAX, DM_VMAX, DM_TMAX, hip[i]);
      hip[i].last_rx_ms = millis();
    }
}

void on_can_wheel(const CAN_message_t& m) {
  for (int i = 0; i < 2; ++i)
    if (m.id == 0x140u + WHEEL[i].id && (m.buf[0] == 0xA1 || m.buf[0] == 0x9C)) {
      motors::lk_parse(m.buf, WHEEL_KT, WHEEL_IQ_FULLSCALE_A, WHEEL_ENC_COUNTS, wheel[i]);
      wheel[i].last_rx_ms = millis();
    }
}

void motors_enable(bool on) {
  uint8_t d[8];
  for (int i = 0; i < 4; ++i) {
    motors::dm_special(on ? 0xFC : 0xFD, d);
    can_send_hip(i, d);
  }
  for (int i = 0; i < 2; ++i) {
    motors::lk_simple(on ? 0x88 : 0x80, d);
    send(can3, 0x140 + WHEEL[i].id, d);
  }
}

// ------------------------------------------------------------------ Pi link
void handle_frame(uint8_t type, const uint8_t* p, uint8_t len) {
  if (type == link::MSG_CMD && len == sizeof(link::Cmd)) {
    link::Cmd c;
    memcpy(&c, p, sizeof(c));
    cmd.mode = c.mode;
    cmd.estop = c.flags & 1;
    cmd.jump_seq = c.jump_seq;
    cmd.v = c.v_mm_s * 1e-3f;
    cmd.yaw_rate = c.yaw_mrad_s * 1e-3f;
    cmd.height = c.height_mm * 1e-3f;
    cmd.roll = c.roll_mrad * 1e-3f;
    cmd.pitch = c.pitch_mrad * 1e-3f;
    cmd.jump_height = c.jump_h_mm * 1e-3f;
    cmd.jump_mode = c.jump_mode;
    cmd.jump_dist = c.jump_dist_mm * 1e-3f;
    last_cmd_ms = millis();
  } else if (type == link::MSG_CALIBRATE && out.state == bolt::ST_OFF) {
    store_calibration();
  } else if (type == link::MSG_EYES && len == sizeof(link::Eyes)) {
    link::Eyes e;
    memcpy(&e, p, sizeof(e));
    eyes_expr = e.expression;
    eye_r = e.r; eye_g = e.g; eye_b = e.b;
    analogWrite(PIN_HEADLIGHT, e.headlight);
    analogWrite(PIN_IR_LIGHT, e.ir_light);
  }
}

void send_telemetry(float batt_v, uint16_t cliff[2]) {
  link::Telem t{};
  t.t_ms = millis();
  t.state = (uint8_t)out.state;
  const bool estop = digitalReadFast(PIN_ESTOP_SENSE);
  const bool lost = (millis() - last_cmd_ms) > CMD_LOST_S * 1000;
  uint8_t fault = 0;
  int8_t tmax = -100;
  for (int i = 0; i < 4; ++i) {
    if (hip[i].err >= 8 || millis() - hip[i].last_rx_ms > 100) fault |= 1 << i;
    tmax = max(tmax, hip[i].t_rotor);
  }
  for (int i = 0; i < 2; ++i) {
    if (millis() - wheel[i].last_rx_ms > 100) fault |= 1 << (4 + i);
    tmax = max(tmax, wheel[i].temp);
  }
  t.flags = (out.contact[0] ? 1 : 0) | (out.contact[1] ? 2 : 0) | (estop ? 4 : 0) |
            (batt_v < BATT_LOW_V ? 8 : 0) | (lost ? 16 : 0) | (fault ? 32 : 0) | (calibrated ? 64 : 0);
  t.roll_mrad = in.imu.roll * 1000;
  t.pitch_mrad = in.imu.pitch * 1000;
  t.yaw_mrad = in.imu.yaw * 1000;
  t.gx_mrad_s = in.imu.gx * 1000;
  t.gy_mrad_s = in.imu.gy * 1000;
  t.gz_mrad_s = in.imu.gz * 1000;
  t.v_mm_s = out.ds * 1000;
  t.s_mm = out.s * 1000;
  t.L_mm_x10[0] = out.L[0] * 10000;
  t.L_mm_x10[1] = out.L[1] * 10000;
  t.theta_mrad = 0.5f * (out.theta[0] + out.theta[1]) * 1000;
  t.batt_mv = batt_v * 1000;
  for (int i = 0; i < 4; ++i) t.sonar_mm[i] = sonars.mm[i];
  t.cliff_mm[0] = cliff[0];
  t.cliff_mm[1] = cliff[1];
  t.motor_temp_max = tmax;
  t.motor_fault_mask = fault;
  t.wheel_mNm[0] = out.wheel[0] * 1000;
  t.wheel_mNm[1] = out.wheel[1] * 1000;
  float hm = 0;
  for (float h : out.hip) hm = max(hm, fabsf(h));
  t.hip_mNm_max = hm * 1000;
  t.yaw_odo_mrad = (int16_t)(fmodf(yaw_unwrapped, 32.767f) * 1000);
  uint8_t buf[sizeof(t) + 6];
  const size_t n = link::encode(link::MSG_TELEM, &t, sizeof(t), buf);
  Serial.write(buf, n);
}

// ------------------------------------------------------------------ setup
void on_tick() { tick = true; }

void setup() {
  Serial.begin(2000000);           // USB CDC (baud ignored)
  pinMode(PIN_ESTOP_SENSE, INPUT_PULLUP);
  pinMode(PIN_HEADLIGHT, OUTPUT);
  pinMode(PIN_IR_LIGHT, OUTPUT);
  pinMode(PIN_BUZZER, OUTPUT);
  analogReadResolution(12);
  eyes.begin();
  eyes.set(Eyes::SLEEPY, eye_r, eye_g, eye_b);
  eyes.update(0);

  can1.begin(); can1.setBaudRate(1000000); can1.enableFIFO(); can1.enableFIFOInterrupt(); can1.onReceive(on_can_hip);
  can2.begin(); can2.setBaudRate(1000000); can2.enableFIFO(); can2.enableFIFOInterrupt(); can2.onReceive(on_can_hip);
  can3.begin(); can3.setBaudRate(1000000); can3.enableFIFO(); can3.enableFIFOInterrupt(); can3.onReceive(on_can_wheel);

  if (!imu.begin()) {
    while (true) {                 // no IMU: never enable the motors
      eyes.set(Eyes::ANGRY, 255, 0, 0);
      eyes.update(millis());
      tone(PIN_BUZZER, 2000, 100);
      delay(500);
    }
  }
  // gyro bias: robot must be still for 1 s after power-up (it is resting on its kickstand pose)
  float g[3], a[3], tmp, asum[3] = {0, 0, 0};
  for (int n = 0; n < 1000; ++n) {
    imu.readAll(g, a, tmp);
    for (int k = 0; k < 3; ++k) { gyro_bias[k] += g[k] / 1000.f; asum[k] += a[k] / 1000.f; }
    delay(1);
  }
  ahrs.init_from_accel(asum[0], asum[1], asum[2]);

  load_calibration();
  static bolt::Controller c(bolt::default_config());
  ctrl = &c;
  sonars.begin(PIN_SONAR_TRIG, PIN_SONAR_ECHO);
  motors_enable(true);

  WDT_timings_t wcfg;
  wcfg.timeout = 100;              // ms
  wdt.begin(wcfg);
  timer.begin(on_tick, 1000000 / CONTROL_HZ);
  tone(PIN_BUZZER, 1500, 80);
}

// ------------------------------------------------------------------ loop
void loop() {
  can1.events(); can2.events(); can3.events();
  while (Serial.available()) {
    if (rx.push(Serial.read())) handle_frame(rx.type(), rx.data(), rx.len());
  }
  sonars.update(micros());
  if (!tick) return;
  tick = false;
  wdt.feed();
  static uint32_t n = 0;
  ++n;
  const float dt = 1.0f / CONTROL_HZ;

  // ---- IMU / attitude
  float g[3], a[3], temp, gb[3], ab[3];
  imu.readAll(g, a, temp);
  for (int k = 0; k < 3; ++k) {
    const int s = IMU_AXIS_MAP[k];
    gb[k] = IMU_AXIS_SIGN[k] * (g[s] - gyro_bias[s]);
    ab[k] = IMU_AXIS_SIGN[k] * a[s];
  }
  ahrs.update(gb[0], gb[1], gb[2], ab[0], ab[1], ab[2], dt);
  ahrs.euler(in.imu.roll, in.imu.pitch, in.imu.yaw);
  float dyaw = in.imu.yaw - yaw_prev;
  if (dyaw > PI) dyaw -= TWO_PI;
  if (dyaw < -PI) dyaw += TWO_PI;
  yaw_unwrapped += dyaw;
  yaw_prev = in.imu.yaw;
  in.imu.gx = gb[0]; in.imu.gy = gb[1]; in.imu.gz = gb[2];
  // vertical specific force in the world frame (used for free-fall / impact detection)
  const float cr = cosf(in.imu.roll), sr = sinf(in.imu.roll), cp = cosf(in.imu.pitch), sp = sinf(in.imu.pitch);
  in.imu.ax = ab[0]; in.imu.ay = ab[1];
  in.imu.az = -sp * ab[0] + cp * sr * ab[1] + cp * cr * ab[2];
  in.dt = dt;

  // ---- legs / wheels
  for (int s = 0; s < 2; ++s) {
    in.leg[s].phi1 = hip_phi(2 * s);
    in.leg[s].phi4 = hip_phi(2 * s + 1);
    in.leg[s].dphi1 = hip_dphi(2 * s);
    in.leg[s].dphi4 = hip_dphi(2 * s + 1);
    in.leg[s].wheel_vel = WHEEL[s].sign * wheel[s].vel;
  }

  // ---- battery / safety
  static float batt_v = 24.f;
  batt_v += (analogRead(PIN_BATT) * 3.3f / 4095.f * BATT_DIVIDER - batt_v) * 0.002f;
  in.battery_v = batt_v;
  const bool estop_hw = digitalReadFast(PIN_ESTOP_SENSE);
  const float since_cmd = (millis() - last_cmd_ms) * 1e-3f;
  bolt::Command c = cmd;
  if (since_cmd > CMD_TIMEOUT_S) { c.v = 0; c.yaw_rate = 0; c.jump_seq = cmd.jump_seq; }
  if (batt_v < BATT_LOW_V) c.v = constrain(c.v, -0.5f, 0.5f);
  if (batt_v < BATT_CRIT_V || estop_hw || !calibrated) c.mode = bolt::MODE_OFF;
  if (!calibrated) c.estop = 1;

  ctrl->step(in, c, out);

  // ---- motor commands (pure torque; tiny kd for smoothness)
  uint8_t d[8];
  for (int i = 0; i < 4; ++i) {
    const float tq = HIP[i].sign * out.hip[i];
    motors::dm_mit(0, 0, 0, 0.02f, tq, DM_PMAX, DM_VMAX, DM_TMAX, d);
    can_send_hip(i, d);
  }
  for (int i = 0; i < 2; ++i) {
    motors::lk_torque(WHEEL[i].sign * out.wheel[i], WHEEL_KT, WHEEL_IQ_FULLSCALE_A, d);
    send(can3, 0x140 + WHEEL[i].id, d);
  }

  // ---- slower tasks
  static uint16_t cliff[2] = {400, 400};
  if (n % (CONTROL_HZ / TELEMETRY_HZ) == 0) {
    cliff[0] = sharp_mm(analogRead(PIN_CLIFF_L));
    cliff[1] = sharp_mm(analogRead(PIN_CLIFF_R));
    send_telemetry(batt_v, cliff);
  }
  if (n % 33 == 0) {
    uint8_t ex = eyes_expr;
    if (!calibrated) ex = Eyes::ANGRY;
    else if (since_cmd > CMD_LOST_S) ex = Eyes::LOST;
    else if (out.state == bolt::ST_FALLEN) ex = Eyes::SLEEPY;
    else if (out.state >= bolt::ST_CROUCH && out.state <= bolt::ST_LAND) ex = Eyes::HAPPY;
    eyes.set(ex, eye_r, eye_g, eye_b);
    eyes.update(millis());
  }
}

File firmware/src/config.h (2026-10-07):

// BOLT firmware - hardware configuration (Teensy 4.1).
// Everything you may need to change for YOUR build is in this file.
#pragma once
#include <stdint.h>

// ----------------------------------------------------------------- loop
constexpr uint32_t CONTROL_HZ = 1000;           // balance loop
constexpr uint32_t TELEMETRY_HZ = 100;          // to the Raspberry Pi
constexpr float CMD_TIMEOUT_S = 0.30f;          // no command from the Pi -> stop & hold balance
constexpr float CMD_LOST_S = 3.0f;              // ... and show "lost link" eyes

// ----------------------------------------------------------------- pins
// CAN buses (each needs its own SN65HVD230 3.3 V transceiver, 120R at the far end)
//   CAN1  TX 22 / RX 23  -> left hip motors  (DM-J4310 x2)
//   CAN2  TX  1 / RX  0  -> right hip motors (DM-J4310 x2)
//   CAN3  TX 31 / RX 30  -> wheel motors     (LK MF9025 x2)
constexpr uint8_t PIN_IMU_CS = 10;              // ICM-42688-P on SPI (11 MOSI, 12 MISO, 13 SCK)
constexpr uint8_t PIN_IMU_INT = 9;
constexpr uint8_t PIN_EYES = 29;                // WS2812B rings (2 x 12 LEDs, chained) via WS2812Serial
constexpr uint8_t PIN_HEADLIGHT = 33;           // PWM -> logic-level MOSFET -> 2 x 1 W white LEDs
constexpr uint8_t PIN_IR_LIGHT = 36;            // PWM -> MOSFET -> 850 nm IR LEDs (night vision)
constexpr uint8_t PIN_BUZZER = 37;
constexpr uint8_t PIN_ESTOP_SENSE = 32;         // HIGH = e-stop loop open (pressed)
constexpr uint8_t PIN_BATT = 16;                // A2: 100k / 6.8k divider from VBAT
constexpr uint8_t PIN_CLIFF_L = 14;             // A0: Sharp GP2Y0A21YK0F (chin, 30 deg fwd of down)
constexpr uint8_t PIN_CLIFF_R = 15;             // A1
// ultrasonic sensors (RCWL-1601 / HC-SR04P - 3.3 V compatible!)
constexpr uint8_t PIN_SONAR_TRIG[4] = {2, 3, 4, 5};        // front-left, front, front-right, rear
constexpr uint8_t PIN_SONAR_ECHO[4] = {24, 25, 26, 27};

// ----------------------------------------------------------------- motors
// DM-J4310-2EC, MIT mode.  Set with the DM debugging tool:
//   CAN ID (slave) 0x01..0x04, master ID 0x11..0x14, 1 Mbit/s, PMAX 12.5, VMAX 30, TMAX 10,
//   CAN timeout 50 ms (motor disables itself if the Teensy stops talking)
struct HipMotorCfg {
  uint8_t bus;        // 1 or 2
  uint16_t id;        // slave id (command)
  uint16_t master;    // feedback id
  float sign;         // +1 / -1 : maps motor positive rotation to +phi (CCW in the x-z plane)
};
constexpr HipMotorCfg HIP[4] = {
    {1, 0x01, 0x11, -1.f},   // left  front  (phi1)
    {1, 0x02, 0x12, -1.f},   // left  rear   (phi4)
    {2, 0x03, 0x13, +1.f},   // right front  (phi1)   right side is mirrored
    {2, 0x04, 0x14, +1.f},   // right rear   (phi4)
};
constexpr float DM_PMAX = 12.5f, DM_VMAX = 30.f, DM_TMAX = 10.f;

// Mechanical calibration pose: legs fully folded against the printed end-stops.
// phi1/phi4 in that pose (from design/kinematics.py at L = L_min - 0.005, theta = 0)
constexpr float CAL_PHI1 = 0.4005f;   // rad
constexpr float CAL_PHI4 = -3.5421f;  // rad (same branch the controller uses: phi4 in (-2pi, 0))

// LK-TECH MF9025v2 on CAN3, IDs 1 and 2 (frame id 0x140 + id), 1 Mbit/s
struct WheelMotorCfg { uint16_t id; float sign; };
constexpr WheelMotorCfg WHEEL[2] = {{1, +1.f}, {2, -1.f}};   // left, right (mirrored)
constexpr float WHEEL_KT = 0.32f;            // Nm/A  - CHECK your motor's datasheet
constexpr float WHEEL_IQ_FULLSCALE_A = 16.5f;// iq = +-2048 <-> +-16.5 A (MF series)
constexpr float WHEEL_ENC_COUNTS = 65536.f;  // 16-bit encoder (some batches: 16384)

// ----------------------------------------------------------------- IMU mounting
// IMU axes -> body axes (x fwd, y left, z up).  Default: chip x fwd, y left, z up.
constexpr int8_t IMU_AXIS_MAP[3] = {0, 1, 2};
constexpr int8_t IMU_AXIS_SIGN[3] = {+1, +1, +1};

// ----------------------------------------------------------------- power
constexpr float BATT_DIVIDER = (100.f + 6.8f) / 6.8f;
constexpr float BATT_LOW_V = 21.0f;          // 6S: 3.5 V/cell -> warn, slow down
constexpr float BATT_CRIT_V = 19.8f;         // 3.3 V/cell -> sit down & power off motors

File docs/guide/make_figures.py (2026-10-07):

#!/usr/bin/env python3
"""Figures for the beginner's guide (docs/guide/*.md).   python3 docs/guide/make_figures.py"""
import json
import math
import os
import sys

import matplotlib
matplotlib.use("Agg")
import matplotlib.pyplot as plt  # noqa: E402
import numpy as np  # noqa: E402
from matplotlib.patches import Circle, FancyArrowPatch, FancyBboxPatch, Rectangle  # noqa: E402

HERE = os.path.dirname(os.path.abspath(__file__))
ROOT = os.path.dirname(os.path.dirname(HERE))
OUT = os.path.join(HERE, "img")
os.makedirs(OUT, exist_ok=True)
sys.path.insert(0, os.path.join(ROOT, "design"))
import kinematics as K  # noqa: E402
from params import FINAL as P, HIP_MOTOR, WHEEL_MOTOR  # noqa: E402

l1, l2, l5, R = P["thigh"], P["shin"], P["hip_spacing"], P["wheel_radius"]


# ---------------------------------------------------------------- 1. five-bar poses
def fivebar():
    fig, axs = plt.subplots(1, 4, figsize=(16, 5.2), dpi=110)
    poses = [(P["L_min"], 0.0, "crouched  L = 0.13 m"), (P["L_nom"], 0.0, "standing  L = 0.22 m"),
             (P["L_max"], 0.0, "stretched  L = 0.35 m"), (P["L_nom"], math.radians(20), "leg angled  θb = +20°")]
    for ax, (L, th, title) in zip(axs, poses):
        p1, p4 = K.inverse(L, th, l1, l2, l5)
        f = K.forward(p1, p4, l1, l2, l5)
        A, E = (l5 / 2, 0), (-l5 / 2, 0)
        B, D, C = f["B"], f["D"], f["C"]
        ax.add_patch(Rectangle((-0.12, -0.02), 0.24, 0.09, fc="#ffd23f55", ec="#c79a00"))
        ax.text(0, 0.045, "body", ha="center", fontsize=8, color="#8a6d00")
        ax.plot([A[0], B[0]], [A[1], B[1]], color="#1f77b4", lw=5, solid_capstyle="round", label="thighs (driven)")
        ax.plot([E[0], D[0]], [E[1], D[1]], color="#1f77b4", lw=5, solid_capstyle="round")
        ax.plot([B[0], C[0]], [B[1], C[1]], color="#ff7f0e", lw=4, solid_capstyle="round", label="shins (passive)")
        ax.plot([D[0], C[0]], [D[1], C[1]], color="#ff7f0e", lw=4, solid_capstyle="round")
        ax.plot([0, C[0]], [0, C[1]], "--", color="#2ca02c", lw=1.6, label="virtual leg L, θb")
        ax.add_patch(Circle(C, R, fc="#22222233", ec="#222"))
        offs = {"A": (4, 14), "E": (-30, 14), "B": (5, 5), "D": (-38, 5), "C": (8, -12)}
        for (pt, nm, col) in ((A, "A", "#1f77b4"), (E, "E", "#1f77b4"), (B, "B knee", "#444"),
                              (D, "D knee", "#444"), (C, "C foot / wheel axle", "#2ca02c")):
            ax.plot(*pt, "o", color=col, ms=7, zorder=5)
            ax.annotate(nm, pt, textcoords="offset points", xytext=offs[nm[0]], fontsize=8, weight="bold")
        ax.text(0.0, 0.13, f"φ1 = {math.degrees(p1):.0f}°   φ4 = {math.degrees(p4):.0f}°", fontsize=8.5,
                color="#1f77b4", ha="center")
        ax.text(0.0, -0.43, "A = front hip motor, E = rear hip motor", fontsize=7.5, ha="center", color="#555")
        ax.set_title(title, fontsize=10)
        ax.set_aspect("equal")
        ax.set_xlim(-0.26, 0.26)
        ax.set_ylim(-0.45, 0.17)
        ax.grid(alpha=0.25)
    axs[0].legend(fontsize=7.5, loc="lower left")
    fig.suptitle("The 5-bar leg (seen from the robot's right side, front = right). Two motors at A and E drive the thighs;\n"
                 "moving them TOGETHER changes the leg length, moving them the SAME WAY swings the leg.", fontsize=11)
    fig.tight_layout()
    fig.savefig(os.path.join(OUT, "fivebar_poses.png"))
    plt.close(fig)


# ---------------------------------------------------------------- 2. leg force vs length
def leg_force():
    Ls = np.linspace(P["L_min"], P["L_max"], 60)
    dLdphi, Fmax = [], []
    for L in Ls:
        p1, p4 = K.inverse(L, 0, l1, l2, l5)
        J = K.jacobian(p1, p4, l1, l2, l5)
        # straight push: dphi1 = -dphi4 ; F dL = T1 dphi1 + T4 dphi4  with |T| = peak
        g = abs(J[0][0]) + abs(J[0][1])
        dLdphi.append(abs(J[0][0]))
        Fmax.append(2 * HIP_MOTOR["peak_torque"] / g)
    fig, ax = plt.subplots(1, 2, figsize=(12, 4.2), dpi=110)
    ax[0].plot(Ls, np.array(dLdphi) * 1000, lw=2)
    ax[0].set_xlabel("virtual leg length L [m]"); ax[0].set_ylabel("dL/dφ  [mm per rad]")
    ax[0].set_title("Leg 'gear ratio': how much L moves per motor radian")
    ax[1].plot(Ls, Fmax, lw=2, color="#d62728", label="max leg force (both motors at 7 Nm)")
    ax[1].axhline(P["components"]["battery_6S_5000"][0] * 0 + 4.2 * 9.81 / 2, color="#555", ls="--",
                  label="force to just hold the body (≈ 21 N per leg)")
    ax[1].set_xlabel("virtual leg length L [m]"); ax[1].set_ylabel("force along the leg [N]")
    ax[1].set_title("Why it can jump: 4-8x the holding force per leg")
    ax[1].legend(fontsize=8)
    for a in ax:
        a.grid(alpha=0.3)
    fig.tight_layout()
    fig.savefig(os.path.join(OUT, "leg_force.png"))
    plt.close(fig)
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

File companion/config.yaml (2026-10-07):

# BOLT companion configuration (Raspberry Pi 5)
teensy_port: /dev/ttyACM0        # Teensy 4.1 over USB
gps_port: /dev/ttyAMA2           # u-blox M10 puck on UART2 (GPIO4/5) - enable dtoverlay=uart2-pi5
app_port: 8080                   # phone app: http://bolt.local:8080
road_graph: maps/roads.geojson   # optional: OSM road lines for shortest-path routing (see docs)
mavlink:
  enabled: true
  # Mission Planner on your laptop listens on UDP 14550. Use its IP, or broadcast:
  url: udpout:255.255.255.255:14550
settings:
  cruise_speed: 1.2              # m/s on missions
  line_speed: 0.8                # m/s line following
  line_color: red
  height: 0.22                   # standing leg length (m)
  crawl_height: 0.135
  wp_radius: 1.0                 # m, waypoint reached
  auto_lights: true              # headlight + IR when the camera sees darkness
  step_tread_default: 0.6

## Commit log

2026-10-07 BOLT wheel-legged robot: CAD, MuJoCo sim, controller, firmware, companion brain, app, wiring
    - design/: single-source parameters (V1-V3 iterations) and 5-bar kinematics
    - cad/: parametric printable parts (STL) generated with manifold3d
    - sim/: MuJoCo model, LQR gain-schedule design, test suite, software-in-the-loop demos
    - firmware/: Teensy 4.1 real-time controller (shared with the sim), CAN motor drivers
    - companion/: Raspberry Pi brain (line following, A* routing, MAVLink, app server)
    - app/: installable phone controller (PWA)
    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
    [assembly_nominal_pose.stl, battery_tray.stl, belly_pan.stl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]
2026-10-07 Docs, simulation report, vision step locator, end-stop pegs, final results
    - docs/01-06: design rationale + COM, BOM, wiring and settings, simulation
    report with V1->V3 iteration results, print/build guide, software guide
    - sim: report generator, final test-suite results (strict push criterion,
    top-speed tracking criterion), brain-in-the-loop demos (line day/night,
    obstacle detour + halt, Mission Planner mission with re-route)
    - companion: camera-based step-edge locator (experimental), bolt_cli tool,
    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
    [assembly_nominal_pose.stl, electronics_sled.stl, shell_front.stl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]
2026-10-07 Add beginner's guide: design process, physics, linkages, CAD, simulation, electronics, code
    docs/guide/ (8 chapters + figures generated by make_figures.py):
    - how the project was made, step by step
    - physics: inverted pendulum, Lagrangian model, LQR, gain scheduling,
    slopes, turning, jump energy, motor limits, IMU fusion
    - 5-bar linkage: DOF, forward/inverse kinematics with worked numbers,
    Jacobian and virtual work, structure and materials
    - parametric CAD, simulation setup, test suite, V1->V3 iterations and
    the controller bug diary
    - electronics from first principles with the design's numbers
    - code walkthrough with real CAN and link frame bytes, change recipes
    Also corrects the leg-f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
    [make_figures.py]
